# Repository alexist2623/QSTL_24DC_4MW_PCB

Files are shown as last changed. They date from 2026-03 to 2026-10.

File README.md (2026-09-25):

# QSTL carrier PCB

Latest PCB revision, 2026-09-25: two **M1** clearance mounts at the ZIF end, with 1.20 mm plated drills, 1.60 mm lands and 17.40 mm center pitch. Centers are (1.05,1.20) and (18.45,1.20) mm. Direct GND, no thermal relief or paste. Board outline, original six mounts, L2/L4 GND clearance, routing, masks, pin assignments and blind-via spans are preserved. Saved/reopened Altium DRC has zero violations across 16 checked rules, zero unconnected lines, and all 37 nets independently connected. See [validation](QSTL_24DC_4MW_PCB/docs/ZIF_M1_mount_validation.json), [current PCB Top](QSTL_24DC_4MW_PCB/docs/PCB_Top_current.png), and [fresh Gerber/drill ZIP](QSTL_24DC_4MW_PCB/fabrication/JLCPCB_HDI_20260925/QSTL_24DC_6RF_HDI_Gerber_20260925.zip). The ZIP has 96 through holes and 480 L5-L6 blind holes. Native OutJob retains its 20260924 working directory; `script/pcb_end_mounts_20260925/package_m1_cam.py` validates and copies the fresh output to the 20260925 delivery. No new supplier upload was made.

The [current Inventor M1 review](QSTL_24DC_4MW_PCB/Mechanical_Assembly/ZIF_M1_Review/README.md) uses supplied **KS B 1021 M1 x 4** slotted round/pan-head screws (pitch 0.25 mm, head diameter 2.00 mm). Nominal housing clearance is 0.627624 mm, and the centered cable has **0.30 mm clearance to each drilled hole**; see the [dimensioned view](QSTL_24DC_4MW_PCB/Mechanical_Assembly/ZIF_M1_Review/ZIF_Cable_Hole_Clearance.png). Only user-permitted head/cable contact remains in the native fit. Cable height and deformation are not fully verified; this is a nominal fit check. M1.6 and M2 review folders are historical.

Open [QSTL_24DC_4MW_PCB.PrjPcb](QSTL_24DC_4MW_PCB/QSTL_24DC_4MW_PCB.PrjPcb) in Altium Designer. The original project contains six active RF channels, 18 DC-only QD pads and six RF bias inputs. ZIF and SMP are on Top; QD, R0603 and C0402 are on Bottom. All eight SMP positions, six original mounting holes and the 19.5 x 67.9 mm board outline are preserved.

Read [DESIGN_REQUIREMENTS.md](QSTL_24DC_4MW_PCB/docs/DESIGN_REQUIREMENTS.md) before further edits. Helpers are in [script/](script/README.md); the reference PCBs remain read-only.

## QD cavity and pad geometry

The Bottom-entry non-plated pocket is 4.3 x 4.3 mm, centred at (9.75,42.50) mm, with R0.5 internal corners and 1.2 mm depth. It is a fabrication-defined blind pocket, not a through-board cutout or a rendered 3D cavity. Its outline is on Mechanical 2 and its English depth note is on Mechanical 3.

QD pad rows have moved outward by 0.2 mm. The inner pad-end opening is 4.7 x 4.7 mm and the nominal cavity-to-pad gap is 0.2 mm. Pad sizes remain 1.0 x 0.5 mm with 0.7 mm pitch along each row. Pads 1 and 24 remain on the upper edge. The original QD footprint library matches the saved board.

The 4.7 mm inner square is free of GND on L2/L3/L4/L5/L6; Top GND remains under the pocket. RF and DC do not cross the cavity.

## RF and routing stack

From the QD side the stack is **RF / GND / DC / GND / DC / GND**, physically L6/L5/L4/L3/L2/L1. RF uses 0.11 mm width with a 0.2 mm coplanar GND gap, following the supplied 50-ohm JLCPCB HDI calculator geometry. The native stack matches the specified copper/dielectric thicknesses for JLCH06161HN1-1078. Fabricator material Dk, finished copper, mask and width compensation still require confirmation; this is not an impedance simulation or measurement. Delay matching to 1 ps remains deferred.

| Input | Series C / bias R | QD pad | Bias ZIF pin |
|---|---|---:|---:|
| SMP1 | C1 / R1 | 9 | 48 |
| SMP2 | C2 / R2 | 6 | 46 |
| SMP3 | C3 / R3 | 1 | 42 |
| SMP4 | C4 / R4 | 24 | 8 |
| SMP5 | C5 / R5 | 12 | 4 |
| SMP6 | C6 / R6 | 18 | 2 |

SMP7/8 centre pins remain NC. All 24 DC nets use physical ZIF even contacts **2, 4, ..., 48**. Contact **50** and every odd contact remain NC. PCB, schematic and QD symbol-library assignments are synchronized. [PIN_MAPPING.csv](QSTL_24DC_4MW_PCB/docs/PIN_MAPPING.csv) contains the complete correspondence. Each RF path passes through its resistor RF-side pad centre without a separate resistor branch stub. All 12 redundant capacitor pad through-vias are removed.

There are 480 solid GND shield vias: 243 along RF routes, 171 around R/C groups, and 66 in SMP signal rings. They span L6-L5 only, with 0.10 mm holes and 0.25 mm lands. Straight fences use nominal 0.15 mm land-edge spacing (0.40 mm centre pitch). The RF clearance is measured from the RF copper edge to the laser-hole edge: 0.33 mm, corresponding to a 0.435 mm centre offset and 0.255 mm land clearance. Each active SMP uses an equal-angle 13-position grid at radius 0.88 mm; two symmetric RF-exit positions are omitted, leaving 11 vias with 0.421 mm chord spacing. R/C fences stay outside each complete two-pad/body envelope.

The remaining 48 through vias comprise 18 QD DC, six DC-side resistor and 24 ZIF fanout vias. QD RF pads 1/6/9/12/18/24 have no vias because their signals stay on Bottom. R1-R6 each have one via on DC pad 2; the six unused RF-side pad 1 vias have been removed. RF pad 1 connects entirely on Bottom, preserving the through-pad RF path without a via stub. DC uses one internal layer per net, 12 nets on each of L2/L4, with no extra transition vias. DC width is 0.125 mm; Top ZIF escapes are 0.15 mm. The central bus pitch is 0.6 mm and the two internal layers share XY routing space. Straight tracks remain XY/45-degree and RF bends use tangent arcs. Two adjacent DC trunks were offset locally by 0.10/0.05 mm to preserve clearance after the QD move.

## Solder mask and paste

Upper R3/C3 and R4/C4 moved upward by 2.0 mm, giving 2.05 mm minimum clearance to QD pads. After the earlier upward and inward adjustments, both lower pairs now sit at 70% of their previous distance from the X=9.75 mm board centreline. R1/C1 moved another 1.365001 mm inward, and R5/C5 another 1.470000 mm inward, as rigid pairs with Y, spacing and rotations preserved. Pair pad-envelope centres are X=12.935000 and X=6.319999 mm. RF/DC endpoints, the two resistor DC vias, rectangular masks and shield fences follow the new positions. The two DC terminations were simplified to one 45-degree approach on their existing L4 layer; no pin remapping or transition via was needed.

The QD Bottom wire-bond field is unmasked. All six R/C groups now have rectangular solder-control areas extending 0.90 mm beyond their pad-group bounds, increased from 0.30 mm. The Bottom ZIF fanout-via array has a rectangular mask boundary with 0.40 mm land margin. RF outside the QD field retains its protected mask strip. SMP solder-control masks remain. All six mounting lands and their surrounding rings are unmasked on both faces and join GND polygons directly, without thermal relief. Shield vias retain explicit tenting overrides in protected areas.

No via-specific paste primitives are present. Paste is disabled on all 40 SMP and eight mounting pads; the 101 SMD pad apertures are preserved. SMP mask remains; mounting mask removal is separately authorized by the later user instruction.

## Current validation and outputs

The saved original PCB contains 22 components, 149 pads, 37 named nets, 228 signal tracks, 20 RF arcs and 528 vias. Save/reopen verification reports **zero connection lines and zero violations across 16 enabled Altium DRC rules**. An independent graph verifies all 37 nets and the actual L5-L6 shield spans. The current native schematic compile reports zero violations and matching assignments. The current PCB/CAM reports are `docs/ZIF_M1_mount_validation.json`, `docs/connection_validation.json` and `fabrication/JLCPCB_HDI_20260925/CAM_validation.json`. Earlier reports below retain their historical revision hashes.

[Saved-board validation](QSTL_24DC_4MW_PCB/docs/DC_Even_ZIF_validation.json) | [Connectivity](QSTL_24DC_4MW_PCB/docs/connection_validation.json) | [Altium DRC](QSTL_24DC_4MW_PCB/docs/DC_Even_ZIF_DRC.html) | [Schematic validation](QSTL_24DC_4MW_PCB/docs/schematic_validation.json)

[Current DC routing](QSTL_24DC_4MW_PCB/docs/DC_Even_ZIF.png) | [ZIF contact detail](QSTL_24DC_4MW_PCB/docs/DC_Even_ZIF_detail.png)

[R/C mask detail](QSTL_24DC_4MW_PCB/docs/RC_mask_detail.png) | [ZIF mask detail](QSTL_24DC_4MW_PCB/docs/ZIF_mask_detail.png)

[RF and shields (preceding revision)](QSTL_24DC_4MW_PCB/docs/RF_only.png) | [QD detail (preceding revision)](QSTL_24DC_4MW_PCB/docs/QD_detail.png) | [Board overview (preceding revision)](QSTL_24DC_4MW_PCB/docs/layout.png)

[Fabrication companion package](QSTL_24DC_4MW_PCB/fabrication/RF50_QD_cavity/README.md) contains the Bottom Blind Slots documentation, stack data and JLCPCB notes. The separate 2026-09-22 Gerber/HDI quote package predates the current DC remap. Regenerate the complete CAM package before production; the prior upload does not contain this change.

Current reports are DC_Even_ZIF.json, DC_Even_ZIF_validation.json, validation.json, connection_validation.json, schematic_validation.json, placement_mask_validation.json, DC_Even_ZIF_DRC.html, native_paste_audit.txt and native_reopen_check.txt. Earlier RF/DC/model/mask reports and images are historical and retain their earlier revision hashes; do not use them as current signoff.

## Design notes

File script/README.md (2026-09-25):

# PCB working scripts

The latest M1 ZIF-end mounts, native save/reopen audit, Inventor standard-hardware fit review and fresh CAM package are in [pcb_end_mounts_20260925/](pcb_end_mounts_20260925/README.md). The current Gerber ZIP is under `fabrication/JLCPCB_HDI_20260925/`. Native L2/L4 GND pour work is in [dc_ground_pour_20260924/](dc_ground_pour_20260924/README.md). Completed Rev E DWG refresh is in [dwg_gerber_refresh_20260924/](dwg_gerber_refresh_20260924/README.md). Earlier CAM/quote records are historical.

The current 2026-09-23 DC remap is in `dc_even_zif_20260923/`: physical J1 contacts 2..48 even only, with pin 50 and every odd contact NC. `FixZIFPads.pas` records the required `SetState_InNet` update and native connectivity rebuild. Saved-file connectivity, schematic correspondence, DRC, preserved RF/mask geometry and DC previews are verified there. Mutation scripts are one-time records; do not rerun them against a different starting revision.

The complete native Altium CAM package and JLCPCB HDI quote record from 2026-09-22 are generated/validated by `jlcpcb_hdi_quote_20260922/package_cam.py`. `ReopenAudit.pas` reopens the original saved board and runs native DRC without changing the design. Quote evidence is stored in `QSTL_24DC_4MW_PCB/fabrication/JLCPCB_HDI_20260922/`.

Create and run helper code inside this repository's `script/` directory. Write Markdown, code comments and technical annotations in English. Communicate with the user in Korean.

Read [DESIGN_REQUIREMENTS.md](../QSTL_24DC_4MW_PCB/docs/DESIGN_REQUIREMENTS.md) and [AGENTS.md](../AGENTS.md) before editing the original `QSTL_24DC_4MW_PCB/` project.

Current lower R/C pair movement to 70% of the previous centreline distance and QD RF-via removal are in `lower_rc_70pct_20260921/`. The preceding removal of unused resistor RF vias is in `remove_resistor_rf_vias_20260921/`. The preceding R/C placement, rectangular-mask and hole-edge shield work is in `rc_mask_clearance_20260921/`. The preceding component-fence/mount work is in `shield_rc_ring_20260921/`; earlier dense fences are in `shield_spacing_20260921/`. The preceding RF50, QD pad/cavity and mask work is in `rf50_hdi_milling_20260920/`. Previous mask work is in `mask_ground_20260920/`; previous RF/DC routing work is in `rf_six_inward_20260920/`. `_support/` contains local parsing, rendering and schematic helpers; older revision names there do not denote a separate final project.

Use `script/.venv/Scripts/python.exe -X utf8` with `requirements.txt`. Native Altium scripts must target the original project and be followed by save/reopen checks. Python validators read saved documents. Current reports must match the saved PCB SHA-256.

Previous mutation scripts such as `ApplyRF6.pas`, `FixRF6.pas`, `AdjustRF6.pas`, `FinalDC.pas` and `FixModels.pas` are one-time change records. They assume a specific starting state and must not be rerun blindly. The preceding via-paste validator is historical: the latest user instruction explicitly removes via-specific paste apertures while retaining normal SMD paste.

Keep reference designs read-only, avoid extra DC transition vias, and preserve the current RF/soldering masks and non-Top QD GND exclusions during later edits.

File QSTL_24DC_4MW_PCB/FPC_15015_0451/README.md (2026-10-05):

# Molex 15015-0451 FPC reconstruction

Manufacturing documentation (reviewed 2026-10-05): [DRC and manufacturability](../docs/FPC_DRC_AND_MANUFACTURABILITY.md) and [order specification](../docs/FPC_ORDER_SPECIFICATION.md). The saved copper remains 18 um; 12 um is an unimplemented alternative. The current contact gap does not meet JLCPCB's regular 18 um spacing requirement. Archived zero-violation reports are not fabrication approval.

Created 2026-10-02 for the Molex 502598-5193 carrier connector. Open `FPC_15015_0451.PrjPcb` in Altium Designer. This is a separate cable project; the carrier PCB and schematic are unchanged.

## Scope and nominal dimensions

The editable PCB reproduces the public nominal cable outline and staggered, same-face contact pattern. It is not Molex's proprietary production artwork or a certified replacement cable. All 51 conductors are present, including contacts unused by the carrier.

| Feature | Implemented nominal value |
| --- | --- |
| Part | Molex 15015-0451 / 0150150451 |
| Length | 101.60 mm; marketed as 102 mm |
| Width | 15.60 mm |
| Circuit count / pitch | 51 / 0.30 mm |
| First / last contact centre | 0.30 / 15.30 mm across the width |
| Contact face | Type A; both ends on Top |
| Corner radius | R0.20 mm; native arc outline segments |
| Exposed contact length | 3.00 mm at each end |
| Back stiffener length | 4.00 mm at each end |
| Contact neck / finger width | 0.10 / 0.30 mm |
| Body conductor width | 0.20 mm |
| Contact transition stations | 0.15, 0.25, 1.10, 1.20, 2.00 and 2.10 mm from the end |
| Copper | 18 micrometres, one conductive layer |
| Base PI + adhesive | 45 micrometres |
| Coverlay PI + adhesive | 50 micrometres |
| End stiffener + adhesive | 150 micrometres, on the back |
| Contact thickness requirement | 0.20 +/- 0.03 mm |
| Surface finish specified by source | Hard gold at least 0.0508 micrometres over nickel at least 2.54 micrometres |

The base/copper/coverlay body sums to 0.113 mm. The exposed end sums to 0.213 mm before plating, within the published 0.20 +/- 0.03 mm end requirement. The 1 mm coverlay/stiffener overlap sums to 0.263 mm before plating. These layer sums use the published nominal composite thicknesses; adhesive compression and detailed production tolerances are not known.

## Altium representation

- Top Layer contains the 51 copper nets. Each end array is a native component with 51 numbered pads and copper regions that define the staggered fingers. The small native pad rectangles lie entirely within their corresponding copper regions.
- Top Solder is used as the **coverlay opening artwork**, not a solder-resist application instruction. Two full-width 3 mm end openings expose the mating fingers.
- The stored master/substack is flex, with one copper layer, the PI base and the upper coverlay. No bottom copper, bottom solder mask, holes or vias are present.
- Mechanical 2, named **Back stiffener boundary**, defines the two 4 mm back stiffener extents. Stiffeners are fabrication annotations, not separate native rigid-flex substacks or 3D solids. Their material/thickness is specified in this document and the review section drawing.
- Mechanical 1 contains English fabrication annotations. No printed silkscreen is required. All contact pad paste generation is disabled.
- `contact_mapping.csv` labels matching physical conductors A1-B1 through A51-B51, viewed from the same global mating face. These cable labels do not imply the pin-number orientation of two separately installed connectors; connector orientation must be considered when wiring an assembly.
- The 0.0707 mm clearance rule follows the drawing's opposed 45-degree stagger transitions: 0.10 / sqrt(2) = 0.0707107 mm. Straight body trace clearance is 0.10 mm. This is the geometry of the copied cable, not a generic PCB fabrication capability claim. No DRC rule was disabled to hide a violation.
- Dielectric constant 3.5 is a modelling placeholder, not a released Molex material property. No controlled-impedance claim is made for this cable.

## Source reconciliation

1. [Molex product page](https://www.molex.com/en-us/products/part-detail/150150451): 51 circuits, 0.30 mm pitch, Type A, 102 mm catalog length; compatibility with the 502598 series.
2. [Current Molex family sales drawing, 150150001PSD000 Rev B, 2023-08-08](https://www.molex.com/content/dam/molex/molex-dot-com/products/automated/en-us/salesdrawingpdf/150/15015/150150445_sd.pdf): staggered contact dimensions, width formula, composite layer thicknesses and end-thickness tolerance. Its searchable dimension text was read; direct local PDF download was unavailable during this task.
3. [Legacy original Molex sales drawing, SD-15015-001 Rev B, 2013-01-23, distributor mirror](https://pdf.icgoo.net/productinfo/allpdf/72b4076c-1cfe-31fc-a247-91ae0da5b5bd.pdf): the 150150451 row explicitly gives 101.6 mm length and 15.6 mm width. The local PDF was rendered and visually checked, including the staggered pattern. A copy is retained under the repository helper's `reference/` directory.
4. [Molex family product specification, PS-15015-001 Rev C](https://www.molex.com/content/dam/molex/molex-dot-com/products/automated/en-us/productspecificationpdf/000/000000/PS-15015-001-001.pdf): electrical/environmental family properties and generic construction requirements.

The sources are not fully consistent: the family product specification has a width formula that adds 0.10 mm, a nominal 0.10 mm conductor width, and a 0.135 mm stiffener value; the sales drawing gives 15.6 mm width, a 0.20 mm body conductor detail, and a 0.150 mm stiffener-plus-adhesive callout. This reconstruction follows the **sales-drawing geometry**. The older drawing has tighter exposure/stiffener tolerances than the current drawing. No unpublished adhesive formulation, copper temper, exact material grade, finished compression, bend lifetime or manufacturing qualification has been inferred. Resolve these differences with the manufacturer before treating the reconstruction as a production-equivalent part.

## Validation and outputs

- `native_validation.txt`: saved-file reopen, one signal layer, zero stored unrouted connections and successful native Altium DRC.
- `Native_DRC.html`: 13 enabled rule checks, zero violations after applying the drawing-derived minimum copper gap.
- `saved_geometry_validation.json`: independent saved-binary geometry checks, including continuity, isolation, pitch, copper layer, stack thicknesses, no vias/drills, and original-carrier hash preservation.
- `FPC_15015_0451_review.png`: review image generated from the saved native copper, with dimensional overview, contact detail and construction section. It is a geometry render, not an Altium screenshot.
- `nominal_geometry.json` and `contact_mapping.csv`: editable nominal specification and physical conductor mapping.

The initial project wrapper contained an invalid optional enum (`ClassGenNCAutoScope=All`). It has been removed from both the saved project and its generator. Native PCB reopen and DRC succeeded; final project-tree registration after this wrapper correction remains unverified because the Altium UI automation repeatedly returned an unresponsive/stale error dialog. The PCB document remains available independently of the project wrapper.

Git delivery of this source cable and the two derivative adapters was requested on 2026-10-03. No Gerber fabrication release, vendor upload or purchase was performed.

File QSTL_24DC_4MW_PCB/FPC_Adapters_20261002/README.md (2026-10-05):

# FPC adapter designs

Manufacturing documentation (reviewed 2026-10-05): [DRC and manufacturability](../docs/FPC_DRC_AND_MANUFACTURABILITY.md) and [order specification](../docs/FPC_ORDER_SPECIFICATION.md). These documents compare saved rules with supplier limits and list the unresolved order settings. Copper remains 18 um per layer; 12 um has not been selected or applied.

Updated 2026-10-02. Open each `.PrjPcb` to load its PCB and schematic. These are additional designs; the original carrier, straight cable and read-only references are preserved.

| Design | Wiring and geometry | Saved validation |
| --- | --- | --- |
| ZIF_to_2xZIF | All 51 contacts branch C.n = A.n = B.n; output tips separated by **70 mm** | Native reopen and DRC: 0 violations; rebuilt connections: 0; 532 independent checks |
| ZIF_to_DSUB25 | Anton's NorComp Micro-D mapping; 25 signals on even ZIF contacts | Native reopen and DRC: 0 violations; rebuilt connections: 0; 87 independent checks |

Both PCBs were rebuilt through Altium's native API and saved normally. The final saved files were reopened in a fresh Altium process for DRC and connection rebuilding. `Native_DRC.html`, `native_validation.txt`, `geometry_validation.json` and `native_status.json` provide the evidence for each board. The review PNGs show actual saved copper with dimensions; they are not Altium screenshots.

The branch's first native schematic compile reported three missing footprint models. Component-specific local `.PcbLib` files were recovered from actual saved PCB pad/region geometry, and explicit model links plus project membership were added. `footprint_recovery.json` records source hashes and coordinate round-trip checks. Native library reload and schematic recompile remain unverified because Altium window activation times out. Independent saved schematic wire/pin correspondence is verified. Restart Altium and run the prepared read-only `CompileOnly.PrjScr` with both final projects open to finish this check; do not run the obsolete offline PCB writers against these final files. Existing `native_compile.txt` reports predate library recovery and are not final compile passes.

The branch's 420 mm overall length and 10 mm strip-to-strip clear gap remain provisional interpretations of the sketch. The DSUB adapter's 40 mm length, 31 mm base and 1.6 mm finished connector-area backing are design assumptions. The original straight 101.6 mm cable was not shortened; the new branch's A-to-B tip separation is 70 mm.

These files are not released for fabrication. The inherited 0.0707105 mm contact gap, small DSUB PTH annulus, fine branch drilling and finished flex/stiffener stack require supplier acceptance. Native DRC confirms the stored design rules, not universal supplier capability.

Git delivery to the existing repository was requested on 2026-10-03. No supplier upload, fabrication release or order was performed.

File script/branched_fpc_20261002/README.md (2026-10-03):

# Adapter helpers and current state

The final designs are under `QSTL_24DC_4MW_PCB/FPC_Adapters_20261002/`.

## Safe verification

- `validate_branch.py` and `validate_dsub.py` read the final saved designs, verify copper/contacts/masks and regenerate dimensional PNGs and geometry reports.
- `CompileOnly.PrjScr` is a read-only native schematic compile/export helper. After restarting Altium, open both final `.PrjPcb` files (including their local footprint libraries), then run `CompileOnly.pas > CompileOnly`. Inspect every violation and compare its recovered pin map with `schematic_correspondence.json` before marking compile as passed.
- `ColdAudit.PrjScr` opens saved final boards, rebuilds connectivity and runs native DRC. It is unnecessary unless the saved boards change. It does not save an altered PCB.
- `recover_footprint_libraries.py` recovers component-specific pad/region geometry, adds explicit schematic model links and project membership. It preserves PCB bytes and stores original schematic/project backups in `before_library_recovery/`. Native library loading remains to be checked.
- `publish_validation_status.py` currently publishes the verified PCB evidence and the pending native library/compile limitation. Update its status logic when native compilation actually passes; do not claim a pass from this documentation writer.

## Obsolete or single-use scripts

Do not run offline PCB writers, `BuildNativeBoth`, `NativeFinish`, `FinalAudit` or `FixViaFlags` against populated final documents. The native PCB rebuild and mask repair have already been applied. `NativeFinish` would add duplicate coverlay regions if repeated. `FinalAudit` performs saves and is superseded by the separate read-only audits. `FixViaFlags` arose from an incorrect interpretation of generic inherited via cache flags; saved native mask overrides already close the via openings. Its attempted unsaved changes must not be promoted to final files.

`native_work/` and `before_native_validation/` contain historical build inputs/results, not final deliverables. The final review PNGs are rendered from actual saved copper, not captured from Altium.

The current Altium sessions did not respond to window activation. The first branch compile reported missing models; libraries were then supplied on disk. Pending work is native reload/compile and verification of those explicit library links. Git delivery was requested on 2026-10-03; the pending native validation remains documented and no fabrication release has been performed.

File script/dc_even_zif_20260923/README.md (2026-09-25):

# Even-contact ZIF DC remap

The original project now uses physical J1 contacts 2, 4, ..., 48 for 18 QD DC inputs and six RF bias inputs. Contact 50, every odd contact and connector mounts 52/53 remain NC. No component positions, pad sizes, RF geometry, shielding or layer stack were changed.

The existing 24 ZIF fanout vias were moved into two rows. Each net uses exactly one internal layer: 12 on L2 and 12 on L4. DC routing below Y=20 mm and local Top/Bottom ZIF mask protection were rebuilt. The schematic, QD symbol library and `docs/PIN_MAPPING.csv` follow the physical even-contact map.

## Saved-file validation

- `audit_connectivity.py`: all 37 nets form continuous copper graphs; 0 saved connection lines, 48 signal through vias and 480 L5-L6 GND blind vias.
- `verify_final.py`: native geometry, clearance rules, QD cavity/GND exclusion, mask, paste and DRC checks.
- `verify_refinements.py`: rectangular masks, solid mounting-hole copper and retained RF shield rings.
- `finish.py`: exact RF/component/pad preservation, even contacts, one internal layer per DC net, XY/45-degree directions, at most 45-degree turns, schematic/PCB/library consistency and actual saved-geometry previews.
- Native save/reopen DRC: 0 violations across 15 enabled rules. Schematic export: 0 reported violations and matching 37 named nets plus 31 singleton NC nets. The API compile-return flag was False and is retained verbatim in `schematic_validation.json`.

The final source hash is in the validation JSON files. Previews are generated from the saved PCB primitives, not synthesized illustrations or screenshots. `DC_Even_ZIF.png` shows the overlay and both DC layers; `DC_Even_ZIF_detail.png` shows all connector contacts and contact 50 NC.

## Change-record workflow

`inspect_baseline.py`, `prepare.py` and `build_native.py` record the initial guarded change preparation. `ApplyEvenDC.pas` performs the native mutation. `prepare_audits.py` promotes the prepared schematic/library after closing them in Altium. `FixZIFPads.pas` explicitly sets the pad InNet flag and rebuilds net connectivity before saving and reopening. This flag is required for previously unconnected pads to retain their new nets on save. All native paths must use single Pascal backslashes to avoid duplicate Free Document aliases.

Mutation scripts and the saved `before.*` files belong to this one-time revision. Do not rerun them blindly against a later PCB. Read-only validators and `finish.py` may be rerun to refresh the matching reports/previews. Prior Gerber/HDI quote packages are historical and were not regenerated or uploaded for this request.

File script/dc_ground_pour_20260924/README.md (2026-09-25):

# DC-layer ground pour and CAM refresh

Completed on 2026-09-24 in the original Altium project. The user confirmed GND pour around existing L2/L4 DC traces. Actual saved-copper images were delivered before CAM generation.

## Saved design

`ApplyGroundPour.pas` initially added `L2_DC_GND` and `L4_DC_GND` through Altium's native PCB API. The user's subsequent widening request was implemented by `WidenGround.pas`: a dedicated 0.20 mm `DC_GND_GAP_0P2` rule applies to GND on L2/L4, and the general 0.15 mm clearance rule excludes that scope. Both polygons were rebuilt and the original PCB was saved, reopened and independently validated.

- L2 grounded copper: 900.799391 mm2; L4: 921.449974 mm2. One connected region per added layer; no floating islands.
- Nominal DC clearance: 0.20 mm; minimum saved signal-copper gap: 0.199997029 mm (within the native 2.54 nm coordinate grid). Trace-only minimum is approximately 0.199999 mm. Trace-to-trace minima remain 0.224998 mm on L2 and 0.274998 mm on L4.
- QD GND exclusion retained on every non-Top layer; Top GND retained.
- Existing tracks, arcs, pads, vias, components, net identities and masks preserved. L1/L3/L5/L6 ground geometry is unchanged. The dedicated DC clearance rule is the only new rule; existing clearance priorities were renumbered and the general rule scope was narrowed accordingly. Native save also materialized zero-valued Manhattan-length statistics and closed the unused polygon terminal vertices onto vertex zero.
- All six mechanical GND annuli connect directly to the new pours without thermal relief.
- All 37 copper nets connected; zero stored connection lines and zero native DRC violations across 16 checked rules after save/reopen, including the new 0.20 mm DC pour rule.
- Native schematic compilation: zero violations; physical assignments match. J1 uses even contacts 2..48; 50 and odd contacts remain NC.
- Existing 480 L5-L6 shield microvias and 48 signal through vias preserved; no added DC transitions.
- Native paste audit checked 147 pads; mask/paste geometry unchanged.

Source SHA-256: `e252bd2d1eb66c667f9d9521f6877922dba3e0579a901d9490fa90835c539c07`.

Pre-widening (0.15 mm pour) SHA-256: `84dcebb1a5cb88b31b997d4bbd6eb5fdd2adb6653206d6d17162d2bf9df86361`. Backup: `before_clearance_0p20.PcbDoc`.

Saved PCB SHA-256: `833555d572fb9945703213acef1ecd809d7eb3ce4a73d5e467c577d3ef70bc90`.

`verify_saved.py` records checks in `validation.json` and `../../QSTL_24DC_4MW_PCB/docs/DC_GND_pour_validation.json`. `preview_ground.py --saved` renders actual native copper to `../../QSTL_24DC_4MW_PCB/docs/DC_GND_pour.png`. Its default mode and `DC_GND_pour_preview.png` are historical proposals, not final results. Mutation scripts are one-time records and must not be rerun against a later board.

## Manufacturing outputs

`prepare_outjob.py` transfers the original project's saved Gerber/NC-drill settings into `HDI_Fabrication.OutJob`. The OutJob belongs to the original project and selects its PCB. Altium regenerated both outputs into `fabrication/JLCPCB_HDI_20260924/Native_CAM` after the 0.20 mm change. Export did not change the PCB.

`package_cam.py` checks timestamps, source hashes, 12 Gerbers, actual GND pours against native geometry, all 94 plated through holes, all 480 laser holes, coordinates/diameters, L5-L6 layer pair, outline and separate Bottom blind-pocket contour. Gerber GND boundaries match native copper within the 0.0002 mm comparison tolerance.

Delivery: `fabrication/JLCPCB_HDI_20260924/QSTL_24DC_6RF_HDI_Gerber_20260924.zip`. Includes requested stack, 50-ohm geometry and Bottom 4.3 x 4.3 x 1.2 mm pocket documentation. Paste/stencil outputs are excluded. `CAM_validation.json` and `Native_DRC.html` accompany the ZIP.

Earlier startup/login and standalone-dialog problems were resolved; the native OutJob completed CAM generation. No supplier upload, new quote, order or Git push was performed for this refresh.

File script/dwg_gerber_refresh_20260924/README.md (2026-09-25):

# Drawing and PCB fabrication refresh - 2026-09-24

## Completed

- Regenerated native plate-only Rev E DWGs from the saved 1.6 mm/C1.6 support geometry, preserving the central deck, device, supplied screws and source CAD files.
- Reopened the combined master and all five single-sheet DWGs. Confirmed five ISO A3 sheets, 46 attached native dimensions without overrides, IPN explosion and removed prose blocks.
- Corrected PowerShell 5.1 source encoding to UTF-8 with BOM for diameter and degree symbols; regenerated all outputs and visually inspected all five PDF pages.
- Delivered `QSTL_Plate_DWG_Package_RevE.zip` in the mechanical model directory. `build_dwg.ps1`, `verify_dwg.ps1` and `package_dwg.py` reproduce the drawing workflow. `DWG_README.md` is the package README source.
- Read-only PCB validation confirmed all 37 copper nets connected, zero saved connections, 24 even ZIF contacts 2..48, pin 50 NC, 48 signal through vias and 480 L5-L6 shield microvias. The pre-pour PCB SHA-256 was e252bd2d1eb66c667f9d9521f6877922dba3e0579a901d9490fa90835c539c07.

## PCB pour and manufacturing outputs completed

The user confirmed GND fill around L2/L4 DC traces and then requested widening its signal clearance to 0.20 mm. Application, saved-copper images and CAM packaging are recorded in `../dc_ground_pour_20260924/README.md`. Images were delivered before new CAM generation.

After startup recovery and user login, `AuditAll.pas` ran against the saved/reopened original PCB. Fresh `reopen_check.txt`, `native_paste_audit.txt`, `schematic_compile.txt` and `fabrication/JLCPCB_HDI_20260924/Native_DRC.html` confirm zero connection lines, zero DRC violations across 16 checked rules, preserved paste and matching schematic assignments. The independent graph verifies all 37 copper nets.

Current PCB SHA-256: `833555d572fb9945703213acef1ecd809d7eb3ce4a73d5e467c577d3ef70bc90`.

`HDI_Fabrication.OutJob` generated fresh Gerber and separate laser/through drills. The validated delivery is `fabrication/JLCPCB_HDI_20260924/QSTL_24DC_6RF_HDI_Gerber_20260924.zip`. Earlier CAM packages remain historical. No supplier upload or Git push was performed.

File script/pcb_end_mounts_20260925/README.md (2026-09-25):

# M1 ZIF-end PCB mounts

Current geometry: MH7/MH8 at X1.05/18.45, Y1.20 mm, with 1.20 mm plated drills, 1.60 mm lands and 17.40 mm pitch. Original outline and six mounts persist. All eight mounts use direct GND, no thermal relief and no paste.

`ApplyM1.pas` records the original-PCB mutation, native repour, save/reopen DRC, paste audit and schematic check. `before_m1.PcbDoc` preserves the immediate M1.6 predecessor. These mutation scripts are one-time records; do not rerun blindly. Historical M2/M1.6 mutation and review scripts are superseded.

Current saved-file validation: `verify_m1_saved.py`, together with `../dc_even_zif_20260923/audit_connectivity.py` and `../dc_ground_pour_20260924/preview_ground.py --saved`. It verifies original pads/routes/vias/components, masks, GND/QD conditions, schematic mapping, DRC and independent continuity.

`generate_m1_round_member.ps1` obtains the genuine KS B 1021 M1 x 4 member. `prepare_m1_review.py` exports saved PCB and embedded connector geometry, plus a dimensional cable envelope. `build_m1_review.ps1` creates/reopens the native Inventor assembly, checks interference/minimum distances, and exports STEP and views. Run Inventor COM scripts using Windows PowerShell 5.1. `render_m1_clearance.py` provides the explicit dimensioned top view; `finalize_m1_review.py` links reports and updates documentation. The output is `Mechanical_Assembly/ZIF_M1_Review/`.

After native Altium `HDI_Fabrication.OutJob` export, `package_m1_cam.py` checks fresh output, 96 through holes, 480 L5-L6 blind holes, DC GND Gerber geometry and preserved silkscreen, then builds the current 18-file ZIP. `prepare_m1_deliverables.py` records how the M1-specific scripts were adapted from the preceding review; do not rerun it over finalized files.

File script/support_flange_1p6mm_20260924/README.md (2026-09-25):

# Support flange 1.6 mm - final revision D

Final user requirements: 1.6 mm rod-contact flanges, full-thickness 45-degree outer bevels (C1.6), plain diameter 3.4 mm mounting holes, original M3 threaded rods and original fastener insertion direction. Flange threading was explicitly cancelled. The central deck remains 4 mm. Preserve the central pocket-reference alignment.

`apply_supports.ps1` updates native supports, eight screw seating transforms, STEP exports and assemblies. Its `before/` snapshot contains the prior 2 mm revision. Do not overwrite that baseline. `set_final_thickness.py` and `prepare_checks.py` are one-time helper preparation records, not regeneration commands.

Run `read_pocket_placement.ps1` to read nested saved transforms, then `verify_assembly.py`, `verify_flange.py` and `verify_native_saved.ps1`. They check valid solids, exact parameter values, native thread absence at flange holes, retained deck threads, protected part hashes, flange geometry, screw seating, actual contact/interference and pocket-reference alignment. The full model has 24 occurrences. The pocket reference is 0.300 mm from the milling floor toward its opening, not the carrier bounding-box centre.

`render_native.ps1` exports the literal cylinder axial view and the support end view. `verify_assembly.py` also makes the labelled STEP section through the pocket, whose centre can be obscured by crossbars in the literal native view.

`build_dwg.ps1` and `verify_dwg.ps1` update/reopen the six native Rev D DWGs (five A3 sheets, 46 associated dimensions). Render and inspect the PDF companion. Run `prepare_delivery.py`, then `package_dwg.py` to produce the current Rev D plate-only drawing package. Keep previous revision ZIPs historical.

The unchanged M3x8 rod screws now project 0.4 mm beyond the provisional 6 mm rods. Their flat head-bearing contact is 67.11%. Existing reference sleeve and tiny device screw fillet/slot intersections remain reported; do not assert that the complete installation is interference-free. No washers, shortened hand-built screws or unrequested reference-part edits were introduced.

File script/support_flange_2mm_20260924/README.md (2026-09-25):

# Support flange revision - 2026-09-24

The user section sketch selects the outer rod-contact flange: 4 to 2 mm and a 45-degree outer bevel. The implemented bevel is C2, spanning the full new flange thickness. The central deck remains 4 mm, and the rod mating plane, device placement and pocket-axis alignment are unchanged.

`apply_supports.ps1` is a one-time guarded mutation with a pre-change backup in `before/`. It saves native support IPTs, assembly placements and STEP exports; moves eight existing rod screws by 2 mm to their new seating plane; and produces native previews. Do not rerun it on already-modified models.

Validation and delivery order:

1. `verify_assembly.py`: full STEP geometry, seating/interference, unchanged reference parts, device alignment and rod contact.
2. `verify_flange.py`: independent requested cuts, valid solids, volume and 20,000 deterministic point classifications per part, bevel planes and actual screw-bearing contact. Coincident-face boolean differences produce invalid kernel results, so they are not used as evidence of equivalence.
3. `verify_native_saved.ps1`: independent saved IPT copies, native features and threads.
4. `build_dwg.ps1`, then `verify_dwg.ps1`: six native Rev C DWGs, five A3 sheets and 46 associated dimensions. Render the PDF companion and inspect all sheets after changes.
5. `prepare_delivery.py`, then `package_dwg.py`: update documentation and create the Rev C plate-only delivery.

The C2 bevel leaves 60.60% of each rod screw flat bearing area in contact. No washers or substitute hardware are introduced. Existing device screw fillet/reference-slot intersections remain in the assembly report. The revision is geometrically checked, not structurally qualified. Rev B delivery files are historical; Rev C is current.

All source comments and design records are English. Original PCB/reference CAD and the flat adapter variant are unchanged by this revision.

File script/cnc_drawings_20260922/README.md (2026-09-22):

# Native split-mount drawing workflow

Run PowerShell helpers under Windows PowerShell with Inventor 2027 running. Use the repository `script/.venv` for Python. The saved Rev B CAD and DWG files are the deliverables. Ignored `tmp/` inspection outputs and pre-edit backups are not part of the delivery.

- `generate_content_center_fasteners.ps1`: generate actual supplied DIN 7991 M3x10 and ISO 4762 M3x8 members, retaining Content Center identity and source hashes.
- `replace_content_center_fasteners.ps1`: update current assembly occurrences and countersink fit; no washers are installed.
- `add_device_relief_grooves.ps1`: one-time native feature creation with a duplicate-feature guard. Do not rerun against the already relieved plate.
- `build_native_dwg.ps1`: rebuild five sheets, six native DWGs and the PDF from saved model geometry and the existing native IPN.
- `verify_native_dwg.ps1` / `verify_standard_hardware.ps1`: reopen validation, native dimensions, standard hardware and thread metadata.
- `package_dwg.py`: verify delivery hashes and produce the Rev B ZIP.
- `inspect_device_reliefs.py` / `verify_device_reliefs.py`: measurement and independent relief checks. The latter uses ignored pre-edit STEP backups from the original session.
- `../probe_rod_inspection/verify_dropped_adapter.py`: saved assembly geometry, placement and interference audit; unresolved device-slot intersections are explicitly reported.

Other helpers retain reference-inspection and prototype history. Older prototype and presentation preparation builders use the superseded illustrative screw and must not overwrite the delivery. Use the current Content Center replacement and native drawing workflow for updates.

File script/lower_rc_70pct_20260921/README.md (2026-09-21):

# Lower R/C placement at 70% of centreline distance

This revision edits the original PCB only. The schematic and QD footprint library remain unchanged; no pin remap is required.

- Translate R1/C1 by -1.36500108 mm X and R5/C5 by +1.46999960 mm X. The centre of each pair's pad envelope is at 70% of its previous distance from X=9.75 mm. Y, spacing and rotations remain unchanged.
- Remove six unused QD RF through vias at pads 1/6/9/12/18/24. Keep 18 QD DC vias, six resistor DC vias and 24 ZIF fanout vias. Capacitor and resistor RF pads remain via-free.
- Reconnect S1/MW1/S5/MW5 using XY/45-degree straight segments with tangent bends. MW1 uses 0.15 mm tangent radii for its small lateral adjustment; other changed bends use 0.30 mm radii. Simplify ZIF21/ZIF02 terminal approaches on their original L4 layer without extra vias.
- Regenerate 0.90 mm rectangular R/C masks and 480 solid L5-L6 shields: 243 RF-fence, 171 R/C-perimeter and 66 equal-angle SMP-ring vias. Preserve the hole-edge offset, no-interpad-via envelopes and cavity/ground/paste requirements.
- Move only the C1 reference label downward by 1.2 mm to resolve the resulting silk collision.

`prepare_move.py` and `prepare_shields.py` reuse the checked-in native geometry writers and guard the expected starting state. `ApplyMove.pas`, `ApplyShields.pas` and `FixLabel.pas` are one-time native mutations; do not rerun on a different revision. `before.PcbDoc` is a local ignored backup.

Validation reads the saved native PCB: exact requested moves and unaffected geometry, 37-net physical copper graph, one internal DC layer per net, XY/45-degree routing, tangent RF bends outside pads, RF paths through resistor pad centres, mask rectangles, 101 normal SMD paste apertures, QD ground exclusions, solid mounting connections, and 15 enabled Altium DRC rules after reopening. All reports must match the current PCB hash. Existing short track endings wholly inside QD pads 1/24 are recorded separately from exposed trace bends.

`publish_outputs.py` refreshes previews and fabrication companion files; this is not a complete production CAM release. `finalize_reports.py` updates current-report pointers after verification.

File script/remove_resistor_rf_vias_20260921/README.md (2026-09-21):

# Remove unused resistor RF-side vias

Saved original PCB SHA-256: `b173b9c072e841f28fbcb25979e917d688061a3a3b2fa08889f660b3afcafd10`.

Removed exactly six 0.50 mm land / 0.25 mm drill through vias, one at RF pad 1 of each R1-R6 (MW1-MW6). The RF path remains on Bottom and passes through the resistor pad centre. Each resistor retains its DC pad 2 via. QD and ZIF vias remain.

Saved counts: 54 signal through vias, 470 L5-L6 GND shield microvias, 524 total vias. All 37 nets are physically connected, with zero stored connection lines and zero violations across 15 enabled native Altium DRC checks after save/reopen.

`before.PcbDoc` is the recovery copy. `prepare.py` and `RemoveRFVias.pas` are one-time scripts guarded against the exact starting revision and six via targets. Only the six vias were removed and GND polygons repoured. Saved component/pad/track/arc/text/fill/net streams and the schematic/library hashes are checked against the baseline. The masks, QD ground exclusions and remaining via locations/spans are validated independently. The requirement is recorded in AGENTS.md and DESIGN_REQUIREMENTS.md to prevent reintroduction.

`audit_connectivity.py`, `verify_final.py`, `verify_refinements.py`, `ReopenAudit.pas` and `AuditPaste.pas` contain validation. `publish_outputs.py` and `finalize.py` refresh previews, documentation and fabrication companion revision hashes. No Git push or supplier submission was performed in this revision.

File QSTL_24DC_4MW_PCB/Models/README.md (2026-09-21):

# Passive 3D model

`R_0603_1608Metric.step` is the generic 1.6 × 0.8 × 0.45 mm resistor from the [official KiCad 3D model library](https://gitlab.com/kicad/libraries/kicad-packages3D/-/blob/master/Resistor_SMD.3dshapes/R_0603_1608Metric.step), retrieved 2026-09-20. It represents the package, not a manufacturer-specific part.

The STEP header credits the 2018 kicadStepUp team and supplies CC BY-SA 4.0 with the KiCad libraries exception for electronic designs. The original header and model are retained without modification. SHA-256: `1875571c326d0d9e96f36b4efeb8094068ef7619f0a449c781caf0b49c2e5861`.

The model is embedded in R1–R6 and `Passives_0603.PcbLib`. Existing capacitor STEP geometry is retained and aligned with the pad axis in the board and `Capacitors_0402.PcbLib`. See `../docs/model_validation.json` for saved-file checks.

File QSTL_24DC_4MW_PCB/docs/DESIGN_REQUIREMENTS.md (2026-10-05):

# User design requirements

Updated 2026-10-05. Later user instructions supersede earlier ones. Read this file before every design-file modification.

## FPC fabrication documentation requested 2026-10-05

- Latest Git delivery request: commit and push the FPC documentation and the requested ZIF-to-two-ZIF-only Altium ZIP. The archive contains only its project, PCB, schematic and required local PCB libraries. Exclude the earlier all-project ZIP and unrelated existing working changes. This supersedes the documentation task's earlier no-commit/no-push scope.
- Terminology clarification: JLCPCB's 2/2 mil line/space at 12 um copper is its published absolute capability limit, not a verified separate orderable process name. Additional line/space charges have not been confirmed. Keep that distinct from the explicitly listed extra charge for the fine two-layer via option.
- Maintain [FPC_DRC_AND_MANUFACTURABILITY.md](FPC_DRC_AND_MANUFACTURABILITY.md) for saved design values, Altium rule coverage, dated JLCPCB FPC limits and unresolved manufacturing issues. Maintain [FPC_ORDER_SPECIFICATION.md](FPC_ORDER_SPECIFICATION.md) for the order settings and fabrication package for the straight FPC, branched FPC and Micro-D adapter. Link both documents from the project READMEs.
- The saved copper target remains 18 um (0.5 oz): one copper layer for the straight cable and two copper layers for each adapter. The user asked about 12 um as an alternative but has not instructed a copper change. Document it as an unimplemented option, including its resistance and mating-thickness implications and its two-/four-layer availability in JLCPCB's published options.
- Distinguish current geometry and stored-rule DRC results from JLCPCB manufacturing compliance. In particular, preserve visibility of the approximately 0.0707105 mm finger gap, special branch drilling, the Micro-D PTH annulus and pending stack/stiffener decisions. Do not label the current files as ready to order, relax rules to claim supplier compliance, or apply the carrier HDI stack/impedance/milling requirements to these separate flex projects.
- This request is for English Markdown documentation. Keep native designs and manufacturing outputs unchanged; do not upload, order, commit or push as part of this documentation-only task.

## Branched FPC and DSUB adapter requested 2026-10-02

- Repository delivery requested 2026-10-03: keep the straight FPC and both adapter projects in the original Git repository and commit/push their designs, local libraries, review images, validation evidence and supporting scripts. They already reside under the repository root, so no relocation is needed. Preserve the documented pending native library/compile checks; Git publication is not fabrication approval. Exclude unrelated CAD work and application-generated working files from this delivery.
- Footprint-link recovery: the first native branch schematic compile reported three missing footprint models. Add component-specific local footprint libraries recovered from the saved PCB pads and contact regions, with explicit schematic model-file links and project membership. Preserve the different A/B/C contact orientations and exact numbered-pad geometry. These libraries now pass independent coordinate round-trip checks; native library loading and recompile remain pending because Altium window activation times out. Preserve the original pre-recovery compile report and do not describe it as a final pass.
- Native DSUB coverlay repair: use one rectangular opening per signal-pin row on each face, with 0.10 mm expansion from the row envelope, instead of unmanufacturably narrow individual coverlay webs. Retain isolated boardlock openings. Accommodate the specified 2.69 mm boardlock drills with a 2.70 mm maximum-hole rule; do not disable the rule. Retain the manufacturer's signal-pad geometry and flag its small PTH annulus for supplier review. This is an editable design, not a JLCPCB fabrication release.
- Native validation repair: recreate the adapter primitives through Altium's PCB API because the offline branch draft produced 51 unrouted reports, 153 antenna reports, 50 hole-spacing reports, 50 mask-sliver reports and a save access violation. Preserve all real violations during repair. Use tented 0.30 mm land / 0.10 mm drill branch vias, consistent with JLCPCB's published two-layer flex extreme capability (extra cost); this restores at least 0.10 mm nominal via-to-trace clearance and increases hole spacing without changing the 70 mm end separation. Supplier process confirmation remains required. Source: https://jlcpcb.com/capabilities/flex-pcb-capabilities
- Latest dimension change: reduce the A-to-B output-tip separation from the provisional 101.6 mm to **70 mm**. Preserve the 420 mm overall draft length and upper output position; move the lower output B upward by 31.6 mm, from Y=318.4 to Y=350 mm. Regenerate routing, coverlay/stiffener boundaries, the saved-file checks and review image. The same-number three-end wiring remains unchanged.
- Confirmed topology: each common-end contact n branches to contact n at both output ends, for all 51 contacts. This is a three-terminal parallel connection for each numbered conductor; do not divide the pin numbers between the outputs. The user explicitly clarified this on 2026-10-02. Keep the Anton reference mapping on the separate DSUB adapter.
- Current native implementation: C is the long Bottom-contact common end; A/B are the two Top-contact outputs. A continuous Top bus joins A and B, and a rounded Bottom bus from C reaches 51 diagonal Top-to-Bottom plated vias in the static junction. Saved via land/drill are 0.30/0.10 mm, superseding the offline draft's 0.35/0.20 mm. Both PCBs were rebuilt with Altium's native API, saved and reopened in a fresh Altium process. Both native DRC reports contain zero violations and rebuilt connection counts are zero. Independent saved-file verification passes 532 branch checks and 87 DSUB checks. Native schematic compilation remains unverified because the Altium validation session stopped responding; independent schematic wire/pin correspondence is verified. This limitation does not waive the remaining native compile check.
- Native mask/paste audit: all contact and through-hole pad paste is disabled. Saved native via mask overrides close apertures on both faces; no explicit via paste-layer primitives exist. The inherited generic via pad-cache booleans do not describe the actual CAM aperture and must not be used alone to infer exposed vias or via paste. Preserve the raw audit output alongside the saved-geometry interpretation. The saved designs have not been released for fabrication: the inherited 0.0707105 mm finger gap, the DSUB footprint's 0.127 mm signal annulus, the fine branch drills and the provisional stack/backing require supplier review.
- Create two additional editable Altium designs from the Molex 15015-0451 contact reconstruction: a ZIF-to-two-ZIF branched flexible board, and a ZIF-to-25-pin-DSUB adapter following the user's sketch. Preserve the original carrier, existing straight cable and read-only reference files.
- Use the same 51-contact, 0.30 mm pitch, 15.60 mm mating width, staggered finger pattern and connector-compatible end thickness. The two right-hand branch contacts are on the illustrated face; the long lower-left contact is on the opposite face, with back stiffeners as drawn. Keep contact numbering/view orientation explicit.
- The sketch requests two copper routing layers and vias at the branch crossover. This is a separate flex-board requirement, not permission to add DC transition vias to the carrier. Use rounded branch transitions and keep vias out of the intended bending zones.
- The sketch marks 20 mm straight end sections, a 10 mm lateral branch dimension and an overall length read as 390 + 30 = 420 mm. Use that overall length provisionally. The right-hand mating-end separation is now explicitly 70 mm, superseding the earlier provisional 101.6 mm. Electrical topology is confirmed by the latest clarification above. Clearly dimension the review so the remaining provisional mechanical interpretation can be reviewed.
- Use the actual saved Anton DSUB-to-ZIF reference netlist for the 25-pin DSUB mapping, including its treatment of odd/even ZIF pins and ground. Do not infer a sequential 1-to-1 mapping.
- Reference inspection: Anton uses NorComp 381-025-112L565 Micro-D. DSUB pins 1..13 map to ZIF 2,6,...50 and pins 14..25 to ZIF 4,8,...48; odd ZIF pins are NC. This new adapter retains reference pin 50; the carrier's separate prohibition on using pin 50 is unaffected. The independent adapter uses a provisional 40 mm length, 31 mm base, manufacturer's 2.69 mm boardlock holes at 24.51 mm pitch and a bonded backing at the DSUB. These are documented design assumptions awaiting any user dimensional correction. Native PCB reopen and DRC pass; native schematic compilation remains pending.
- Keep helper code under script/, verify saved connectivity and mask/coverlay geometry, run native Altium checks where available, and deliver native projects and dimensional review images. Git delivery is authorized by the 2026-10-03 follow-up. No fabrication release or supplier upload is requested.

## SMP density CAD variants requested 2026-10-02

- Latest end-pair correction: the uppermost and lowermost SMP pairs must have the same horizontal centre spacing as well as the existing uniform vertical row pitch. Set both end pairs to X=6.75 / 12.75 mm, giving 6.0 mm horizontal centre spacing and symmetry about X=9.75 mm. This moves only the lower end pair inward by 0.75 mm per connector relative to the last uniform-row version. Retain all seven Y positions and their 6.0 mm pitch. Dimension both end-pair pitches in the review image and verify saved equality and absence of interference. Changes remain CAD-only.
- Latest clarification: tighten and equalize the vertical row spacing of all seven SMP rows, including the uppermost and lowermost added pairs. The user means the Y-direction centre pitch of successive rows, not diagonal centre distances or equal nearest-surface distances. Use a 6.0 mm vertical pitch for the 5.5 mm connector bodies. Set the central row to Y=43.5 mm to avoid SMP-pin intersections with the unchanged Bottom R2/R6 models; the seven row coordinates are Y=25.5, 31.5, 37.5, 43.5, 49.5, 55.5 and 61.5 mm. This reduces the full centre span from 39 to 36 mm and lowers the uppermost pair from Y=62 to 61.5 mm. Preserve the current row X coordinates, connector geometry and mounting height; all SMP occurrences may move in this CAD-only study. Verify uniform saved Y pitch, connector/component clearance and mounting-bore clearance. This supersedes the earlier uneven-row placement and preservation of original SMP Y positions.
- Latest spacing correction: remove connector-to-connector interference in the 14-SMP CAD layout by adjusting longitudinal spacing, and move the upper added pair farther down toward the DSUB end. This supersedes the previous permission to leave SMP intersections in this 14-SMP layout. Retain all 14 connectors, their geometry, mounting height and 2+2+2 arrangement. Prefer longitudinal changes; if the upper pair's horizontal overlap cannot be removed by a common vertical shift, use the minimum symmetric lateral adjustment needed to preserve an aligned pair with a positive gap. Verify all connector pairs using saved B-rep geometry and report the resulting minimum spacing. Preserve the original Altium design, source models and rod assembly.
- Current spacing implementation in the separate CAD study: lower the upper added pair by 2.0 mm to Y=62.0, and spread each outward by 0.5 mm to X=6.75 / 12.75. Retain the central additions and lower additions at their previous positions. Move the lowest original pair SMP5/SMP1 upward by 1.0 mm to approximately Y=28.14, providing clearance to the lower additions without moving them toward the large mounting holes. All other connector positions and heights remain unchanged. These CAD placement changes supersede the earlier instruction to retain all eight original positions, but do not alter the Altium board's pads or drills.
- Latest annotated clarification, now authorized for implementation: add six SMP connectors as 2 + 2 + 2, giving 14 connectors including the existing eight. The indicated locations are an upper pair between the upper mounting holes and upper SMP group, a left/right pair in the central gap between the existing SMP groups, and a lower pair between the lower SMP group and the large mounting holes. The upper and lower added pairs are drawn inward of the existing outer SMP columns; the central additions follow the left/right columns. This supersedes the previous interpretation of additions within every existing horizontal row. Preserve the original eight connectors and create a separate 14-SMP model.
- The sketch contains no exact dimensions. Use symmetric provisional CAD placement centres (mm in the source PCB frame): upper (7.25, 64.00) and (12.25, 64.00); central at the existing left/right column X coordinates and midway between Y=34.34 and 48.84 (approximately Y=41.59); lower (6.00, 23.00) and (13.50, 23.00). These are placement-study choices derived from the sketch, not user-specified dimensions. Preserve the existing SMP geometry, mounting side and height; intersections remain permitted.
- Historical output: two separate mechanical PCB variants were created from the saved DSUB25 PCB CAD with one SMP or two SMPs between each left/right facing pair in all four rows, giving 12 and 16 SMP connectors. Retain those prior outputs separately; they are not the latest annotated six-addition layout.
- This is a CAD-only placement study. Connector intersections are explicitly permitted. Preserve the Altium PCB, schematic, libraries, Gerbers, source STEP and current rod assembly. Do not add electrical pads, routing or substrate holes for the additional connectors.
- Deliver separate STEP models and top/oblique review images. Keep helpers under the repository script folder and record the exact placements and saved-model checks. No Git push is requested.

## Combined rod assembly requested 2026-10-01

- Latest layout request: rearrange all requested PCBs, three gold connectors and the enclosed DSUB device on the existing rods to eliminate placement interference. This supersedes the earlier requirement to preserve the photo reconstruction's PCB positions. Keep the device enclosure/plate/support fastening relationships and use existing rod holes. Preserve source geometry and report any inherited internal fit issues separately from inter-module placement. Retain all requested solid components, suppress illustrative wire/ribbon paths in accordance with the user's no-wire-display preference, and verify the saved assembled geometry before delivery. No Git push is requested.
- Latest enclosure correction: include the existing Bottom/Top_ForFridge device enclosure, lowered central mounting plate, left/right rod supports and supplied standard fasteners with the lower DSUB25 device PCB in the combined rod assembly. Reuse the saved mechanical parts and their mounting relationships; do not leave only a bare PCB. Retain the corrected lower gold-connector depths and omitted rear wires. Check the DSUB replacement against the enclosure/mount and surrounding photo-derived parts, report actual interferences, and regenerate the assembled STEP and review images. Preserve the original source CAD and PCB. No Git push is requested.
- Latest correction: position the two lower gold cylindrical connectors within the rod thickness so that the rods occlude them in a true side view. Remove the illustrative rear wire paths; retain the connector geometry. Preserve the upper connector and the PCB placements. Show a true orthographic side view and a rear detail, and record the revised depth and geometric checks. Any accompanying support-bar adjustment remains photo-estimated placement context, not a verified mounting design.
- Arrange the completed photo-derived DSUB PCB, ZIF PCB, copper-backed filter PCB and three rear gold connectors on the rods according to the supplied photographs. Add the current Altium-derived DSUB25 carrier PCB near the lower rod end.
- Reuse the completed component geometries and the existing rod reference. Preserve the source models and create a separate combined assembly with traceable placement transforms, front/rear/detail views and STEP output.
- The lower carrier is a placement review; any front/rear mounting-face assumption and offset needed to avoid overlap with the filter plate must be recorded. Do not invent verified fasteners, electrical interconnects or production mounting hardware. Check the added carrier against the existing assembly and rod envelope. No Git push is requested.

## DSUB mechanical PCB variant requested 2026-10-01

- Create an additional 3D model of the current saved Altium carrier PCB with a 25-pin DSUB connector replacing its ZIF connector. Use the original Narrow_v4 reference PCB for the DSUB model, position, side and orientation; this is distinct from the photographed electronics reconstruction and the separate Anton adapter.
- Preserve the current PCB outline, cavity, other components and their current placements. Deliver the connector substitution as a separate mechanical model and clearly distinguish it from an electrically rerouted PCB. Do not modify the original Altium PCB, schematic, manufacturing outputs or read-only reference PCB for this model-only request.
- Extract and verify the actual reference connector geometry and placement when available. Provide STEP and preview images, with traceable source hashes and any placement limitations. Keep helpers under the repository script folder. No Git push is requested.

## Photo-based probe electronics models requested 2026-10-01

- Model the photographed DSUB PCB, ZIF PCB, filter PCB above the brown copper plate, and three rear gold cylindrical wire connectors. The user confirmed that the connectors are the two lower units plus the single upper unit connected to the white wires.
- Use the supplied photo collage and its caliper readings, together with available reference CAD/PCB files, as evidence. Keep measured, reference-derived and photo-estimated dimensions distinct. Do not present unreadable measurements or an unconfirmed connector identity as exact.
- Deliver separate 3D parts and an assembled placement review with images. Keep dimensions parameterized so photo estimates can be revised. Preserve the existing carrier PCB, machined split mount, rods and read-only reference files; place this reconstruction in a separate mechanical folder. Helper code belongs in the repository's script folder.
- This request authorizes modeling and local output creation only; it does not request supplier transmission or a new Git push.

## LTspice AC-coupling review requested 2026-09-26

- Latest parameter case: evaluate a 100 nF coupling capacitor and 300 kohm shunt resistor under the same single 100 mV input, and quantify the first 300 us of output decay. Preserve the earlier simulation cases for comparison.
- Previous parameter case: evaluate a 100 nF coupling capacitor and 1 Mohm shunt resistor, with the same single 100 mV input and 300 us decay window. Deliver the voltage-drop graph and retain the previous 10 nF / 300 kohm result for comparison. Use `1Meg` for the resistor value in LTspice.
- Latest follow-up: deliver a graph of the first 300 us after the rising edge and quantify the output voltage drop. Use the saved single-step LTspice data, with time zero at the end of the 1 us rising edge; retain the circuit and non-repeating input.
- Follow-up: run a 300 ms transient simulation, verify the output decay time constant, and deliver the waveform and simulation files. This supersedes the initial circuit-only delivery restriction.
- Prepare and deliver the circuit first, before running the requested voltage-decay measurement: a 10 nF series AC-coupling capacitor followed by a 300 kohm resistor, driven by a 100 mV square wave.
- Initial review interpretation: connect the resistor from the capacitor output to GND and measure OUT relative to GND. Use an ideal voltage source and no additional output load.
- Latest correction: the user explicitly rejected the assumed 50 Hz repetition. Use one 0-to-100 mV rising transition and hold the input high through the 300 ms transient window, with no repeated switching. Retain a 1 ms initial delay and 1 us rise time for the simulation. The single held step is the interpretation communicated to the user for the decay measurement.
- Deliver an editable LTspice schematic in `simulation/LTspice/`. This simulation request does not change the Altium PCB or schematic.

## Language and workspace

- FPC reconstruction implementation (2026-10-02): Molex 15015-0451 sales-drawing geometry uses 101.6 x 15.6 mm, 51 contacts at 0.30 mm pitch, same Top contact face, 3 mm exposed ends and 4 mm back stiffeners. Retain the 0.10/0.30 mm staggered contact neck/finger and 0.20 mm body conductor geometry. Its minimum diagonal gap is about 0.0707107 mm; the 0.0707 mm cable-specific clearance rule is distinct from the carrier's fabrication rules. Record conflicting family-spec width, conductor and stiffener values in the cable README; do not claim proprietary production equivalence. Stiffener extents are fabrication-layer geometry, not native 3D stiffener solids.

- New cable request (2026-10-02): verify Molex 15015-0451, the nominal 102 mm, 51-contact, 0.30 mm pitch Type A FPC, and reproduce its released nominal geometry in a separate editable Altium cable project. Preserve the carrier and read-only references. Reproduce the actual length, staggered same-face contacts, all 51 conductors, reinforcement and specified stack. Resolve catalog rounding using the released drawing; document conflicting or unpublished manufacturing details. Keep helpers under script/, verify saved geometry/connectivity and Altium checks, and deliver native files and a review image. No Git push or fabrication order is requested. This separate cable project is explicitly authorized and is not a replacement carrier revision.

- Write Markdown documents, code comments and technical annotations in English. Use Korean in conversation with the user.
- Edit the original project, PCB and schematic. Do not create a separate V2 project or a final Free Document.
- Keep Python and Altium helper scripts in the repository-root `script/` directory.
- The initial reference PCB and the carrier PCB used to inspect ZIF wiring are read-only.
- Push to Git only when the user requests it.

## PCB fabrication quote requested 2026-09-22

- Regeneration requested 2026-09-24: regenerate the plate-only native DWGs from the current saved 1.6 mm/C1.6 support geometry and deliver a visual drawing preview. Then regenerate PCB Gerbers and separate through/blind drill files from the current even-ZIF 2..48 design, excluding pin 50. Include the Bottom blind-milling layer, existing controlled-impedance stack requirements and fresh saved-design/CAM validation. Preserve the current models and PCB design. This request does not authorize a new order, upload or Git push.

- Export the current original PCB as a complete Gerber and separated drill package, and upload it to the JLCPCB HDI quote interface.
- Quote bare PCBs only, without PCBA or a stencil. Enable controlled impedance for the existing 50-ohm L6 coplanar RF with L5 reference and retain the specified Bottom blind milling pocket.
- Verify the actual L6-L5 blind-via span and its separate laser drill data, including the uploaded layer mapping. Capture the selected ordering options, price and production/shipping lead times. Do not place or pay for a production order.

## Mechanical geometry and placement

- Latest ZIF size correction (2026-09-25): use M1 round/pan-head screws, superseding M1.6. Obtain actual supplied standard hardware, adapt the PCB screw-clearance holes to the confirmed M1 member, and repeat the housing/cable fit check with an explicit hole-to-cable dimensioned top view. Preserve the 19.5 mm board width, electrical routing, direct GND/no-thermal/no-paste mounting treatment and existing six original mounts. Do not silently substitute a larger screw size or custom-model a standard member. Implement using Content Center KS B 1021 M1 x 4, pitch 0.25 mm, head diameter 2.0 mm and head height 0.65 mm. Use 1.2 mm plated clearance drills and 1.6 mm lands at (1.05,1.20) and (18.45,1.20) mm, pitch 17.40 mm. Moving the two end holes 0.55 mm outward gives 0.30 mm nominal cable-to-hole lateral clearance while retaining the board outline; verify the saved dimensions and actual native fit. Implemented and verified: 0.30 mm cable-to-hole clearance per side, 0.627624 mm nominal screw-to-housing distance, no housing/PCB interference, and only permitted head/cable-envelope contact. Saved/reopened DRC: 16 rules, zero violations; independent continuity: 37 nets. Current native review and matching STEP are in Mechanical_Assembly/ZIF_M1_Review. Cable height remains an unverified placement assumption.

- Superseded M1.6 round-head trial (2026-09-25): replace the cylindrical socket-head ISO 4762 review screws with actual supplied standard M1.6 round/pan-head screws. Preserve the approved 1.8 mm PCB holes and existing positions unless the user requests a geometry change. Do not hand-model substitute hardware or add washers. Deliver an enlarged top view that exposes the hole outlines and cable edges, with signed edge-to-edge distances, plus the updated assembled view. Cable-head pressure is permitted, but distinguish it from cable overlap with the drilled holes or screw shanks. This supersedes the earlier ISO 4762 selection below. Implemented with Content Center ISO 7045 H M1.6 x 4 (0.35 mm pitch, 3.2 mm head diameter, 1.3 mm head height). Saved/reopened Inventor finds head-to-housing intersection on both sides. The 15.6 mm cable overlaps each 1.8 mm hole by 0.55 mm in top projection; inside-hole clear width is 14.5 mm. Current positions are unchanged and not interference-free.

- Superseded M1.6 socket-head trial (2026-09-25): MH7/MH8 at (1.60,1.20) and (17.90,1.20) mm, pitch 16.30 mm, plated drill 1.80 mm and land 2.20 mm. Direct GND, no thermal relief or paste, unchanged board outline. Fit review uses unmodified Content Center ISO 4762 M1.6 x 4, pitch 0.35 mm, no washer. Nominal housing gap is only 0.025 mm, less than 0.10 mm radial shank play; housing contact remains possible and tolerance-safe assembly is not confirmed. Cable-head contact is permitted; cable is a dimensional envelope. See Mechanical_Assembly/ZIF_M1p6_Review/README.md.

- Latest PCB mounting request (2026-09-25): add two screw-clearance mechanical holes at the ZIF-side end, at the locations indicated in the user's annotated image. Use direct solid GND connections with no thermal relief, expose the mechanical lands without paste, and preserve the existing six holes and all electrical connectivity. The user subsequently requested M1.5, then explicitly approved changing to M1.6 standard screws after checking the installed ISO 4762 Content Center library. Use M1.6 with 1.8 mm clearance holes and real supplied screw geometry for the fit check. This supersedes the initial M2 implementation. The user confirmed retaining the existing 19.5 mm board width and reducing the hole pitch inward instead of preserving the annotated 17.9 mm pitch. Keep the outline unchanged. Check the matching ZIF cable together with actual supplied M1.6 screw hardware in Autodesk Inventor, including head/cable and connector interference; report the hardware and cable assumptions and any collision. The user explicitly permits the screw heads to press against the cable; do not classify that intended contact alone as a rejection. Continue to check the connector housing, PCB signal copper, hole-edge margins and fastener seating. Then regenerate affected fabrication outputs and show the result.

- Latest rod-fastener change (2026-09-24): replace the eight rod-mounting screws with actual round/button-head M3x8 screws from the installed Autodesk Inventor Content Center. Retain the standard 0.5 mm pitch, existing bearing planes and fastening direction through the 1.6 mm support flanges into the rod threads. Preserve the two device screws, eight countersunk deck screws and all fabricated geometry; do not add washers. Check the supplied head envelope, bearing contact and cylinder interference, and show the updated assembly.

- Latest 1.6 mm flange correction (2026-09-24): reduce both outer rod-contact flanges from 2 mm to 1.6 mm, retaining the 45-degree full-thickness outer bevel (now C1.6). After confirming that the reference rods already have M3 through threads, the user cancelled threading the support flanges. Keep their eight holes as plain 3.4 mm M3 clearance holes and retain fastening through the support into the existing rod threads; do not add flange threads, reverse the joint or alter the original rods. Preserve the central deck, boss, rod mating plane and device placement. Re-measure the PCB pocket-floor +0.300 mm cavity-side reference point against the cylinder axis using saved assembly transforms, and deliver a native axial top view. Update native CAD, STEP and affected DWGs. Retain the supplied standard hardware and report actual seating, tip projection and remaining interference.

- Latest support-end change (2026-09-24): the user's section sketch marks the outer rod-contact support flange, not the central deck. Reduce both marked end flanges from 4 mm to 2 mm and bevel their outer ends with a full-thickness C2 x 45-degree chamfer as drawn. Retain the central deck/boss, rod-contact datum and device/pocket alignment. Update affected native models, assembly references, STEP exports and fabrication/assembly DWGs. Check flange screw seating, real standard screw engagement and the bevel against mounting holes; do not introduce washers or handmade hardware.

- Standard hardware requirement: use the actual M3 fasteners supplied by Autodesk Inventor Content Center. Do not substitute custom simplified screw shapes. Replace the custom M3 hardware in the current split-mount assembly with the appropriate supplied standard families/members, retaining the normal 0.5 mm pitch and checking real head envelopes, clearances and engagement. Preserve the newly requested device relief grooves.
- Implemented hardware: eight DIN 7991 M3x10 deck screws, eight ISO 7380-1 M3x8 button-head rod screws and two ISO 4762 M3x8 device screws from the installed Inventor 2027 Content Center, with unmodified source member files and M3x0.5-6g external thread features. Enlarge the eight 90-degree deck countersinks to 6.6 mm for the actual 0.2 mm head rim and 0.1 mm recessed head face. Preserve internal M3x0.5-6H threads. Cosmetic thread-cylinder overlap is acceptable only within the documented tapped depth and nominal thread diameter. Legacy illustrative fastener builders are historical and must not overwrite this standard-hardware state.
- Latest user correction: do not introduce device washers as an unsolicited clearance fix. Remove the added washers and restore the original screw bearing planes. Keep the reference device unchanged. Report the actual local under-head fillet/slot intersection separately; do not hide it, reshape the standard screw, or add other hardware to claim clearance.

- Latest mounting-interface change: machine two 0.5 mm deep relief grooves in the central plate at the device mounting lips indicated in the user's end-view image. Measure the actual device screw-mounting lip thickness from the saved CAD; groove width must equal that thickness plus 0.3 mm total clearance. Preserve the device, the existing mounting datum and thread locations, and update the affected native model, STEP, fabrication/assembly DWGs and delivery package. Keep comments and drawing annotations in English.
- Implemented relief geometry: measured lip thickness 3.039840616900516 mm; each groove is 3.339840616900516 mm wide, 72 mm long and 0.5 mm deep, with R0.5 closed-end corners. Grooves run along both boss sides at local Y=4..76 mm, Z=3.5..4 mm. The 0.3 mm width allowance extends outward from the unchanged boss contact faces. Preserve the existing carrier placement and M3 axes.

- Latest drawing correction: remove the manually typed BILL OF MATERIALS and ASSEMBLY SEQUENCE blocks shown by the user. Follow the native drawings and presentation in `C:/JeonghyunPark/Workspace/QSTL_M12C_BNC/Enclosure3` for assembly documentation. Show the three-part plate assembly with clear exploded geometry, alignment trails/fastening direction and assembled views instead of prose blocks. Deliver native, editable DWG sheets with correctly sized paper and a saved fit-to-sheet view. Preserve all reference files and fabrication geometry.

- Deliver the split-mount manufacturing and assembly drawings in DWG format. Inspect the user's existing mechanical drawings first and follow their sheet, title-block, projection, dimensioning and annotation conventions. A PDF-only package does not satisfy this requirement. Preserve source/reference drawings and model geometry.

- Limit this DWG package to fabrication of the central plate/boss, left support and right support, plus their screw-fastened three-part assembly. Exclude the cylinder, rod/device installation and sleeve-fit drawings. The three-part exploded/assembled joint drawing remains required.

- Omit the general NOTES block shown by the user, including supplier grade/temper declarations, proposed RFQ tolerances/roughness, release/confirmation text, quantity/TBD statements and STEP-governs boilerplate. Keep material and surface treatment in the title block, dimensional/thread callouts on views, and the actual plate assembly instructions. Do not move the removed notes elsewhere in the drawing.

- Material for the three machined split-mount parts (central plate/boss and both rod supports) is oxygen-free copper (OFC), with no surface treatment or coating. Record the supplier's exact OFC grade and material certificate; do not invent an approved alloy grade, temper or thermal-performance specification. Machined surface roughness remains a separate drawing requirement from surface treatment.

- Prepare a CNC drawing package for the split lowered variant: dimensioned drawings for the central plate with integral boss and both rod supports, plus an exploded assembly drawing, hardware schedule and assembly sequence. Use the saved CAD geometry as the dimensional source. Drawings and notes must be in English. Preserve the models while preparing the drawings; explicitly identify unresolved material, finish, quantities, production tolerances, blind-thread tooling and existing sleeve envelope clashes before manufacturing release. Include STEP files with the drawing package. No ordering, supplier contact or Git push is authorized by this drawing request.

- Split the lowered variant at the deck-to-support interface shown by the user. Use three separately machinable parts: the central deck with its integral device boss, and separate left/right rod supports. Join the central deck to the supports with screws inserted from the outside deck face. Retain the 8.5 mm drop and the aligned pocket reference point. Use 6 mm wide connecting walls to accommodate two rows of M3 assembly screws without changing the 6 x 80 mm rod contact footprints. The initial detail uses four M3 x 10 countersunk screws per support, 20 mm pitch, with heads recessed to preserve the cylindrical envelope. Archive the superseded monolithic lowered adapter; preserve the original flat version unchanged. Verify separate solids, mating faces, screw engagement, saved thread metadata and the assembled centre alignment. Final machining radii and tolerances remain unspecified.

- Add a separate stepped mounting-plate variant while preserving the existing flat plate and its assembly unchanged. Lower the central deck, mounting boss, carrier and device fasteners by 8.5 mm relative to the current arrangement, as in the user's end-view sketch. Keep both rod-contact flanges and rod fasteners at their current locations. Preserve the 80 mm contact length, 4 mm plate/web thickness, 6 mm boss height and bilateral five-hole M3 x 0.5 - 6H rows at 16 mm pitch. Align the point 0.300 mm from the PCB pocket floor toward the cavity opening with the sleeve axis, including the measured +0.139127461912 mm lateral correction of the boss/carrier/device screws. The axis remains X=25.5 mm, Z=3 mm. This additional variant supersedes the earlier instruction to retain only one mechanical arrangement; both requested versions must remain available. Verify actual saved placements, connected solid geometry, contact/interference and centre alignment. Do not change the original holder, PCB, rods or sleeve.

- Preserve the reference 19.5 x 67.9 mm outline, all eight SMP positions and six mechanical mounting holes.
- ZIF and SMP are on Top. QD and all R/C components are on Bottom.
- Preserve the requested QD orientation and pad numbering 1-24.
- The central QD cavity remains 4.3 x 4.3 mm. The latest user correction requires moving the QD pads outward by 0.2 mm, making the square defined by inward-facing pad ends 4.7 x 4.7 mm. Preserve the 1.0 x 0.5 mm pad sizes and 0.7 mm pitch along each row; cavity-to-pad clearance is 0.2 mm.
- Move at most one pad from each side to the upper edge, only if necessary to resolve a corner collision. Current upper pads are 1 and 24.
- Use 0603 resistors and 0402 capacitors. Component rotations must be multiples of 45 degrees.
- Place all six R/C pairs inward as shown by the user. The lower R1/C1 and R5/C5 groups are rotated 90 degrees from the previous arrangement.
- Align capacitor 3D models with their pad axes and use a proper 0603 resistor package model.

## RF and DC connectivity

- RF QD pads are 1, 6, 9, 12, 18 and 24. Preserve the physical positions of the initial four RF channels; QD12 and QD18 are additional RF connections.
- Current mapping: SMP1 to QD9, SMP2 to QD6, SMP3 to QD1, SMP4 to QD24, SMP5 to QD12, SMP6 to QD18. SMP7/8 centre pins are NC.
- Each RF channel has a series capacitor and DC bias resistor. The RF path must pass through the resistor RF-side pad centre without a separate resistor branch stub.
- Use via-in-pad for the 18 QD DC pads and the DC-feeding bias-resistor pads. QD RF pads 1/6/9/12/18/24 connect entirely on Bottom and must have no vias; this supersedes the earlier all-QD-pad via requirement. R1-R6 must have exactly one via each, at DC pad 2. RF pad 1 connects entirely on Bottom and must have no via; do not add a through via to a same-layer RF junction. This explicitly supersedes the former two-vias-per-resistor implementation. RF series capacitors remain entirely on Bottom: remove their redundant through vias to avoid RF stubs. Retain their normal SMD pads and paste. Place R/C close together, with C naturally aligned to the RF path.
- Connect the 18 DC-only QD pads and six RF bias resistors to the 24 even ZIF contacts 2, 4, 6, ..., 48 only, matching Anton's adapter contact convention. Pin 50 is explicitly unused; all odd contacts remain NC. Preserve the actual footprint contact numbering and synchronize the schematic, QD library labels and PCB. This supersedes the previous 1-12 and 15-26 assignment.
- Resolve crossings by changing ZIF assignments in the schematic and PCB together. Each DC net must complete its route on one internal signal layer. Do not add standalone DC layer-transition vias.
- Current even-contact bias assignments: R1=48, R2=46, R3=42, R4=8, R5=4, R6=2. All six resistor DC pads remain connected and all RF pad assignments remain unchanged. The 2026-09-22 Gerber/HDI quote package predates this DC remap and must be regenerated before production.

## Routing and layer stack

- Latest DC pour clearance correction (2026-09-24): increase the L2/L4 GND-pour clearance to non-GND copper from 0.15 mm to 0.20 mm. Persist a dedicated native Altium clearance rule, repour those two polygons, and verify saved/reopened geometry, connectivity and DRC before refreshing images and fabrication outputs. Preserve trace positions, trace-to-trace rules, RF geometry, all other ground layers, masks, pin mapping and vias. The default 0.15 mm non-RF clearance below remains applicable outside this targeted pour rule.

- DC copper-pour request (2026-09-24, confirmed): add GND copper pour around the existing DC tracks on L2 and L4, and send images of both layers before regenerating Gerbers. Preserve the even-contact assignment, single internal layer per net, existing clearances, QD exclusions and blind-via span. Remove unconnected copper islands; do not expand the individual DC signal nets or add DC transition vias.

- From the QD side: RF / GND / DC / GND / DC / GND. Physical layers: L6 RF, L5 GND, L4 DC, L3 GND, L2 DC, L1 GND.
- RF is on Bottom with QD and R/C. RF and DC must not cross the QD interior.
- Straight tracks may only be horizontal, vertical or 45 degrees. RF corners must be tangent curves. Each DC corner must turn at most 45 degrees; do not use a single sharp 90-degree corner.
- Use XY overlap between the two independent DC layers. Preserve clearance to other nets on the same layer and to through-hole pads/vias on every layer.
- Gather DC routes near the board centre. Do not pull them toward large GND holes. Preserve clearance and minimize bends.
- Current DC width is 0.125 mm and Top ZIF escapes are 0.15 mm. RF width changes to 0.11 mm with a 0.2 mm coplanar GND gap, following the supplied JLCPCB 50-ohm HDI calculation. Default non-RF clearance stays 0.15 mm. Central DC bus pitch is 0.6 mm.
- Preserve short RF centreline routes and tangent arcs. The user deferred 1 ps delay matching. Specify 50 ohms as the controlled-impedance target; calculator geometry is not a measured guarantee for connector, component or wire-bond transitions.
- Use the supplied 6-layer 1078 HDI stack: copper 0.035/0.0152/0.0152/0.0152/0.0152/0.035 mm, and dielectric gaps 0.0784/0.55/0.2008/0.55/0.0784 mm. Match L6/L5 to the symmetric L1/L2 calculator geometry. Use the current calculator's actual stack code in fabrication notes.

## Solder mask, paste mask and QD ground exclusion

- The request to remove the green coating means solder-mask removal. Use explicit Top/Bottom Solder openings on general board areas, retaining mask at soldering sites and RF routes.
- QD is a wire-bonding area. Remove Bottom solder mask across its pad field and central cavity. Retain solder-control mask around SMD R/C, ZIF contacts/fanout, SMP signal/ground pins, and retain mask on RF away from the QD bond-pad field. The Top reverse side retains its previous via tenting.
- Preserve mask over RF tracks and tangent curves, including a margin from the RF copper edge. Initial implementation uses a 0.25 mm protected margin. Do not change RF copper to achieve a visual mask change.
- Latest explicit follow-ups: remove every via-specific Top/Bottom Paste aperture and all paste apertures on mechanical mounting pads and SMP pads. Normal SMD component-pad paste openings must remain. This overrides the earlier request for paste apertures on every via.
- The user clarified that removing paste on mechanical parts and SMP does not mean removing their solder mask. Retain SMP solder-control masks; the later explicit mounting-hole request now removes mounting masks.
- Retain via tenting in protected soldering areas. Solder-mask coating and paste-mask stencil apertures are separate features and must be audited separately.
- Remove GND within the QD inner-end square on every copper layer except Top. The updated inner pad-end boundary is x=7.4-12.1 mm and y=40.15-44.85 mm, centred at (9.75,42.5) mm.
- Keep Top GND within that square and retain layer-specific polygon-pour cutouts on L2/L3/L4/L5/L6. The latest user request authorizes a non-through milled pocket from the QD/Bottom face, with a 4.3 x 4.3 mm outer envelope and 1.2 mm depth. This supersedes the earlier instruction not to mill the substrate. Do not create a through-board cutout. Move the QD pads outward as specified above and reconnect their existing via-in-pad fanouts.
- The pocket envelope is x=7.6-11.9 mm, y=40.35-44.65 mm, inset 0.2 mm from each 4.7 mm pad-end boundary. The latest user correction preserves the 4.3 mm QD cavity and moves the pads, superseding the earlier proposal to shrink the cavity to 3.9 mm. Use rounded internal CNC corners and state the cutter radius in the drawing.
- JLCPCB requires a separate Bottom Blind Slots Gerber, side/depth/metallization order fields, a location/section drawing and an order remark naming the layer. Specify a non-plated cavity. Verify the remaining substrate and nearest copper clearance; no production order is authorized.
- Recheck these mask and GND conditions after every subsequent layout or polygon modification.

## Vias and validation

- Extend shield fences around R1-R6 and C1-C6. Treat each two-pad convex hull (including the inter-pad bridge/body area) as a forbidden region for shield-via lands; surround the outside instead of cutting between the pads.
- Active SMP rings must use equal angular increments and symmetric RF exits. Choose an equal-angle grid from the hole-edge clearance radius and nominal 0.40 mm chord pitch. Keep the RF exit gap symmetric; do not retain an obsolete fixed via count when the radius changes.
- Latest mechanical-hole instruction supersedes the earlier protected mounting mask: expose all six mounting lands and their surrounding ring on both solder-mask layers. Connect these GND mounting pads directly to every GND polygon with no thermal spokes/voids. SMP solder-control masks and normal SMD paste remain unchanged; mounting paste remains disabled.

- Add GND shield vias along both sides of RF routes, with nominal 0.15 mm copper-land-edge spacing, equivalent to 0.40 mm centre spacing for the retained 0.25 mm lands. Use chord spacing at curves/rings; larger local gaps are allowed only to preserve pad/hole and RF-exit clearance. This supersedes the previous 2 mm pitch. The latest correction measures three RF widths from the RF copper edge to the laser-drill hole edge, not to the via land. For 0.11 mm RF and 0.10 mm holes, the centre offset is 0.435 mm; the 0.25 mm land edge is 0.255 mm from RF copper.
- Shield vias connect L6/Bottom RF coplanar GND to adjacent L5 GND only. Use laser blind microvias, nominal 0.1 mm drill and 0.25 mm land, with solid connections and no thermal spokes or paste apertures. They must not reach L4/L2 DC layers. Continue the fence inside each active SMP footprint as a ring around its signal centre, leaving the RF escape corridor clear.
- Preserve via-in-pad; component pad mask openings remain distinct from via-specific tent flags. Via-specific paste apertures must be absent.
- Avoid unintended component, pad and routing overlaps. Intentional same-net joints and via-in-pad are allowed.
- Keep PCB, schematic and library pin definitions consistent. Save/reopen and check DRC and retained connection counts. Independently verify actual copper connectivity on all layers.
- Verify solder-mask openings against protected RF/soldering geometry, normal SMD paste preservation, absence of via-specific paste, and GND exclusion on all non-Top layers with Top GND retained.

## Latest placement and rectangular mask refinement

- Centre the device on the plate's longitudinal bisecting plane X=25.5 mm. After its end-for-end reversal, move the device and mating boss together by +2.088496738338 mm in X. The boss's local X minimum becomes 19.794248369169 mm; its width remains 13.5 mm. The device centre is defined by the midpoint of the complete carrier's X bounds. Preserve all hole pitches and the inward-facing mounting arrangement.

- Latest correction supersedes the previous whole-group rotation: attach the plate to the opposite rod face while keeping its boss directed inward between the two rods. The plate occupies Z=-4 to 0 mm; rods remain Z=0 to 6 mm and the boss occupies Z=0 to 6 mm. Keep the screenshot-confirmed device orientation with ZIF uppermost (180-degree in-plane turn). Move this device/boss group inward without turning the boss outward. Rod screws enter from Z=-4 mm toward +Z. Keep only this corrected arrangement as the final assembly.

- Shorten the mounting plate to approximately the complete device length. The unchanged carrier spans 79.43999922 mm along the rods; use an 80 mm plate from assembly Y=135 to 215 mm. Retain its 51 mm width, 4 mm thickness and 13.5 x 6 mm boss cross section. The boss length becomes 72 mm. Keep the existing carrier and occupied screw positions; retain five M3 x 0.5 - 6H holes per boss side at 16 mm pitch (Y=144.82802366515844 through 208.82802366515844 mm) and four rod fasteners per rod at Y=140,160,180,200 mm. This supersedes the longer plate, eight-hole boss rows and 16 rod fasteners. Reversal reviews use the shortened plate.

- Final orientation is the screenshot explicitly confirmed by the user: ZIF is at the upper end and the carrier is rotated 180 degrees in the plate plane, then the complete plate/carrier/fastener group is mounted on the opposite rod face. The confirmed open document was `Orientation_Review/Both_reversed.iam`. Promote this exact placement to the main assembly and retain only this final result. The device uses the opposite threaded boss face at reference Y=160.82802366515844 and 176.82802366515844 mm. The full group reversal is 180 degrees about the rod-axis line X=25.5, Z=3 mm. Preserve rod and sleeve positions, the 80 mm plate and all source part geometry. Archive intermediate alternatives in the script temporary folder.

- Add matching threaded rows to both opposite side faces of the raised device-mounting boss. Each side has eight right-hand M3 x 0.5 - 6H threads at the same 16 mm pitch and aligned Y/Z centres, for 16 threads total. Retain 6 mm modeled bore/thread depth per side and the 13.5 mm boss width, leaving a 1.5 mm solid web between opposed bores. Preserve the existing two device screws, all assembly placements and the sleeve.

- Add a separate open-ended cylindrical sleeve around the H frame: inner diameter 51 mm, outer diameter 54 mm, with its axis through the midpoint of the two rod centre lines. Current frame rod centres are (X,Z)=(3,3) and (48,3) mm, so the sleeve axis is X=25.5 mm, Z=3 mm, parallel to Y. Use 360 mm length matching the rods unless the user specifies another length. Preserve these requested diameters and the existing geometry; measure and report actual intersections rather than silently resizing the sleeve or other parts. Add the sleeve to the current mechanical assembly and keep the standalone part editable.

- Match the Coldfinger-v2 lower device-mounting hole row on the indicated raised boss face: 16 mm centre spacing, right-hand M3 x 0.5 - 6H internal threads. Extend the current two device mounting holes into eight positions at local Y=17.82802366515844 + 16*n mm (n=0..7), retaining the existing two screw locations and unchanged carrier placement. Preserve the solid plate and boss. Record real Inventor thread features, not only plain bores. The reference drawing has an inconsistent 4 mm drill / 6 mm thread depth callout; retain the existing 6 mm model depth rather than copying the contradictory 4 mm pilot depth.

- Latest top-view correction and annotated follow-up: fill both empty longitudinal openings completely, making one solid plate across the rods. The device screw-mounting face must project integrally above this plate. Put this raised boss under the holder body on the inside of its existing flange, matching the PPT end-view silhouette. The follow-up clarifies the missing plate material and projecting mounting face; retain the existing device slots rather than inventing another hole pattern. Preserve the original holder and maximize rod contact. This supersedes the open-frame adapter and the previous boss outside the holder footprint.

- The user identified `assembly_coldfinger_v2.SLDASM` as the combined reference. Its imported assembly confirms that Top_ForFridge mounts by its existing side slots to the narrow Coldfinger-v2 support. Use this side-clamp interface, with the device body exposed. The current concept uses 150 x 6 mm continuous contact on each rod in the free middle bay and two M3 device screws at the existing 16 mm slot pitch. All new thicknesses and fastener details remain provisional; preserve the existing device slots and rod holes.

- Build the user's sketched rod-to-holder adapter as a separate mechanical part and review assembly. Latest correction: do not cover or surround the original device/holder with a broad saddle. Use the hanging and screw-tightened attachment method demonstrated in the read-only ColdFinger DilFridge mechanical v2 reference. Inspect that mechanism before redesigning the adapter. Maximize contact with both rods using extended contact surfaces and distributed clamping, while keeping the device body exposed. Retain the carrier, PCB, and H-frame source models unchanged. Match the rod M3 pattern and use the existing device mounting feature; record provisional dimensions as editable parameters. Do not add or move holes in the reference holder. This supersedes the previous broad raised-saddle adapter.

- Build a separate simplified H-shaped probe support frame from the supplied SO01373.10-Probe-R01.pdf: two copper rods, 360 mm long, 6 mm wide, with 45 mm centre spacing (51 mm overall width and 39 mm clear gap), 33 M3 through-thread locations per rod at 10 mm pitch starting 30 mm below the top. Exclude the upper anchor, lower mechanism and enclosing tube. Use two crossbars at approximately 110 and 270 mm below the top, with estimated 8 mm height. Rod/crossbar front-to-back depth is not dimensioned: use an explicitly provisional 6 mm and retain editable parameters. Model M3 threads as simplified cylindrical openings; do not invent unshown fastener details. Preserve the existing PCB/carrier assembly and save the frame separately in the repository.

- Export the current PCB as a simplified mechanical 3D model for an Inventor assembly. Preserve board outline, thickness, mounting holes, QD pocket, component positions and sides, and component envelope dimensions/heights. Simplify resistor and capacitor models but retain their physical sizes and heights. Fit the SMP/Top PCB face to Bottom.SLDPRT, and the opposite QD/Bottom PCB face to Top_ForFridge.SLDPRT from the read-only Narrow_V3_24DC_8MW reference folder. The latest user clarification selects Top_ForFridge instead of Top.SLDPRT and accepts the SMP overlaps for this assembly pass. Save the derived assembly and models in the working repository; do not overwrite the reference SolidWorks files.

- Latest lower-pair refinement: move R1/C1 and R5/C5 toward X=9.75 mm so that each pair centre is at 70% of its previous distance from this board centreline. Define each pair centre by the union of its pad envelopes. Move each pair rigidly in X, preserving Y, spacing and rotations; reconnect RF and DC and rebuild masks and shielding. This is an additional move from the saved revision immediately before this request.
- Move upper R3/C3 and R4/C4 upward by 2.0 mm, away from the QD bond pads. Move both lower R1/C1 and R5/C5 upward by 1.0 mm, as confirmed by the user. Additionally move R1/C1 inward by 0.35 mm. Preserve pair spacing and rotations; reconnect RF/DC without adding transition vias.
- Increase the retained solder-control margin around each R/C group from 0.30 to 0.90 mm. Use exact axis-aligned group rectangles, not rounded convex-hull patches. Preserve normal SMD pad openings and paste, RF coverage and the unmasked QD field.
- Cover the complete Bottom ZIF fanout-via array with a rectangular solder-mask area, extending 0.40 mm beyond its via lands.

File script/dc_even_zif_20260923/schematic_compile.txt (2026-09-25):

PROJECT=C:\JeonghyunPark\Workspace\QSTL_24DC_4MW_PCB\QSTL_24DC_4MW_PCB\QSTL_24DC_4MW_PCB.PrjPcb
COMPILE_START
COMPILE_RESULT=False
VIOLATION_COUNT=0
NET_COUNT=68
NET=ZIF48|PINS=2
PIN=J1-48
PIN=R1-2
NET=ZIF46|PINS=2
PIN=J1-46
PIN=R2-2
NET=ZIF44|PINS=2
PIN=J1-44
PIN=Q1-2
NET=ZIF42|PINS=2
PIN=J1-42
PIN=R3-2
NET=ZIF40|PINS=2
PIN=J1-40
PIN=Q1-3
NET=ZIF38|PINS=2
PIN=J1-38
PIN=Q1-14
NET=ZIF36|PINS=2
PIN=J1-36
PIN=Q1-4
NET=ZIF34|PINS=2
PIN=J1-34
PIN=Q1-15
NET=ZIF32|PINS=2
PIN=J1-32
PIN=Q1-5
NET=ZIF30|PINS=2
PIN=J1-30
PIN=Q1-16
NET=ZIF28|PINS=2
PIN=J1-28
PIN=Q1-7
NET=ZIF26|PINS=2
PIN=J1-26
PIN=Q1-17
NET=ZIF24|PINS=2
PIN=J1-24
PIN=Q1-8
NET=ZIF22|PINS=2
PIN=J1-22
PIN=Q1-19
NET=ZIF20|PINS=2
PIN=J1-20
PIN=Q1-10
NET=ZIF18|PINS=2
PIN=J1-18
PIN=Q1-20
NET=ZIF16|PINS=2
PIN=J1-16
PIN=Q1-11
NET=ZIF14|PINS=2
PIN=J1-14
PIN=Q1-21
NET=ZIF12|PINS=2
PIN=J1-12
PIN=Q1-13
NET=ZIF10|PINS=2
PIN=J1-10
PIN=Q1-22
NET=ZIF08|PINS=2
PIN=J1-8
PIN=R4-2
NET=ZIF06|PINS=2
PIN=J1-6
PIN=Q1-23
NET=ZIF04|PINS=2
PIN=J1-4
PIN=R5-2
NET=ZIF02|PINS=2
PIN=J1-2
PIN=R6-2
NET=S6|PINS=2
PIN=C6-1
PIN=SMP6-1
NET=S5|PINS=2
PIN=C5-1
PIN=SMP5-1
NET=S4|PINS=2
PIN=C4-1
PIN=SMP4-1
NET=S3|PINS=2
PIN=C3-1
PIN=SMP3-1
NET=S2|PINS=2
PIN=C2-1
PIN=SMP2-1
NET=S1|PINS=2
PIN=C1-1
PIN=SMP1-1
NET=NetSMP8_1|PINS=1
PIN=SMP8-1
NET=NetSMP7_1|PINS=1
PIN=SMP7-1
NET=NetJ1_53|PINS=1
PIN=J1-53
NET=NetJ1_52|PINS=1
PIN=J1-52
NET=NetJ1_51|PINS=1
PIN=J1-51
NET=NetJ1_50|PINS=1
PIN=J1-50
NET=NetJ1_49|PINS=1
PIN=J1-49
NET=NetJ1_47|PINS=1
PIN=J1-47
NET=NetJ1_45|PINS=1
PIN=J1-45
NET=NetJ1_43|PINS=1
PIN=J1-43
NET=NetJ1_41|PINS=1
PIN=J1-41
NET=NetJ1_39|PINS=1
PIN=J1-39
NET=NetJ1_37|PINS=1
PIN=J1-37
NET=NetJ1_35|PINS=1
PIN=J1-35
NET=NetJ1_33|PINS=1
PIN=J1-33
NET=NetJ1_31|PINS=1
PIN=J1-31
NET=NetJ1_29|PINS=1
PIN=J1-29
NET=NetJ1_27|PINS=1
PIN=J1-27
NET=NetJ1_25|PINS=1
PIN=J1-25
NET=NetJ1_23|PINS=1
PIN=J1-23
NET=NetJ1_21|PINS=1
PIN=J1-21
NET=NetJ1_19|PINS=1
PIN=J1-19
NET=NetJ1_17|PINS=1
PIN=J1-17
NET=NetJ1_15|PINS=1
PIN=J1-15
NET=NetJ1_13|PINS=1
PIN=J1-13
NET=NetJ1_11|PINS=1
PIN=J1-11
NET=NetJ1_9|PINS=1
PIN=J1-9
NET=NetJ1_7|PINS=1
PIN=J1-7
NET=NetJ1_5|PINS=1
PIN=J1-5
NET=NetJ1_3|PINS=1
PIN=J1-3
NET=NetJ1_1|PINS=1
PIN=J1-1
NET=MW6|PINS=3
PIN=C6-2
PIN=Q1-18
PIN=R6-1
NET=MW5|PINS=3
PIN=C5-2
PIN=Q1-12
PIN=R5-1
NET=MW4|PINS=3
PIN=C4-2
PIN=Q1-24
PIN=R4-1
NET=MW3|PINS=3
PIN=C3-2
PIN=Q1-1
PIN=R3-1
NET=MW2|PINS=3
PIN=C2-2
PIN=Q1-6
PIN=R2-1
NET=MW1|PINS=3
PIN=C1-2
PIN=Q1-9
PIN=R1-1
NET=GND|PINS=32
PIN=SMP1-2
PIN=SMP1-3
PIN=SMP1-4
PIN=SMP1-5
PIN=SMP2-2
PIN=SMP2-3
PIN=SMP2-4
PIN=SMP2-5
PIN=SMP3-2
PIN=SMP3-3
PIN=SMP3-4
PIN=SMP3-5
PIN=SMP4-2
PIN=SMP4-3
PIN=SMP4-4
PIN=SMP4-5
PIN=SMP5-2
PIN=SMP5-3
PIN=SMP5-4
PIN=SMP5-5
PIN=SMP6-2
PIN=SMP6-3
PIN=SMP6-4
PIN=SMP6-5
PIN=SMP7-2
PIN=SMP7-3
PIN=SMP7-4
PIN=SMP7-5
PIN=SMP8-2
PIN=SMP8-3
PIN=SMP8-4
PIN=SMP8-5
COMPLETE

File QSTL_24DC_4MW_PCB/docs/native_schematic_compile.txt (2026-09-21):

PROJECT=C:\JeonghyunPark\Workspace\QSTL_24DC_4MW_PCB\QSTL_24DC_4MW_PCB\QSTL_24DC_4MW_PCB.PrjPcb
COMPILE_START
COMPILE_RESULT=False
VIOLATION_COUNT=0
NET_COUNT=68
NET=ZIF26|PINS=2
PIN=J1-26
PIN=R4-2
NET=ZIF25|PINS=2
PIN=J1-25
PIN=R2-2
NET=ZIF24|PINS=2
PIN=J1-24
PIN=Q1-14
NET=ZIF23|PINS=2
PIN=J1-23
PIN=R3-2
NET=ZIF22|PINS=2
PIN=J1-22
PIN=Q1-15
NET=ZIF21|PINS=2
PIN=J1-21
PIN=R1-2
NET=ZIF20|PINS=2
PIN=J1-20
PIN=Q1-16
NET=ZIF19|PINS=2
PIN=J1-19
PIN=Q1-2
NET=ZIF18|PINS=2
PIN=J1-18
PIN=Q1-17
NET=ZIF17|PINS=2
PIN=J1-17
PIN=Q1-3
NET=ZIF16|PINS=2
PIN=J1-16
PIN=Q1-19
NET=ZIF15|PINS=2
PIN=J1-15
PIN=Q1-4
NET=ZIF12|PINS=2
PIN=J1-12
PIN=Q1-20
NET=ZIF11|PINS=2
PIN=J1-11
PIN=Q1-5
NET=ZIF10|PINS=2
PIN=J1-10
PIN=Q1-21
NET=ZIF09|PINS=2
PIN=J1-9
PIN=Q1-7
NET=ZIF08|PINS=2
PIN=J1-8
PIN=Q1-22
NET=ZIF07|PINS=2
PIN=J1-7
PIN=Q1-8
NET=ZIF06|PINS=2
PIN=J1-6
PIN=Q1-23
NET=ZIF05|PINS=2
PIN=J1-5
PIN=Q1-10
NET=ZIF04|PINS=2
PIN=J1-4
PIN=R6-2
NET=ZIF03|PINS=2
PIN=J1-3
PIN=Q1-11
NET=ZIF02|PINS=2
PIN=J1-2
PIN=R5-2
NET=ZIF01|PINS=2
PIN=J1-1
PIN=Q1-13
NET=S6|PINS=2
PIN=C6-1
PIN=SMP6-1
NET=S5|PINS=2
PIN=C5-1
PIN=SMP5-1
NET=S4|PINS=2
PIN=C4-1
PIN=SMP4-1
NET=S3|PINS=2
PIN=C3-1
PIN=SMP3-1
NET=S2|PINS=2
PIN=C2-1
PIN=SMP2-1
NET=S1|PINS=2
PIN=C1-1
PIN=SMP1-1
NET=NetSMP8_1|PINS=1
PIN=SMP8-1
NET=NetSMP7_1|PINS=1
PIN=SMP7-1
NET=NetJ1_53|PINS=1
PIN=J1-53
NET=NetJ1_52|PINS=1
PIN=J1-52
NET=NetJ1_51|PINS=1
PIN=J1-51
NET=NetJ1_50|PINS=1
PIN=J1-50
NET=NetJ1_49|PINS=1
PIN=J1-49
NET=NetJ1_48|PINS=1
PIN=J1-48
NET=NetJ1_47|PINS=1
PIN=J1-47
NET=NetJ1_46|PINS=1
PIN=J1-46
NET=NetJ1_45|PINS=1
PIN=J1-45
NET=NetJ1_44|PINS=1
PIN=J1-44
NET=NetJ1_43|PINS=1
PIN=J1-43
NET=NetJ1_42|PINS=1
PIN=J1-42
NET=NetJ1_41|PINS=1
PIN=J1-41
NET=NetJ1_40|PINS=1
PIN=J1-40
NET=NetJ1_39|PINS=1
PIN=J1-39
NET=NetJ1_38|PINS=1
PIN=J1-38
NET=NetJ1_37|PINS=1
PIN=J1-37
NET=NetJ1_36|PINS=1
PIN=J1-36
NET=NetJ1_35|PINS=1
PIN=J1-35
NET=NetJ1_34|PINS=1
PIN=J1-34
NET=NetJ1_33|PINS=1
PIN=J1-33
NET=NetJ1_32|PINS=1
PIN=J1-32
NET=NetJ1_31|PINS=1
PIN=J1-31
NET=NetJ1_30|PINS=1
PIN=J1-30
NET=NetJ1_29|PINS=1
PIN=J1-29
NET=NetJ1_28|PINS=1
PIN=J1-28
NET=NetJ1_27|PINS=1
PIN=J1-27
NET=NetJ1_14|PINS=1
PIN=J1-14
NET=NetJ1_13|PINS=1
PIN=J1-13
NET=MW6|PINS=3
PIN=C6-2
PIN=Q1-18
PIN=R6-1
NET=MW5|PINS=3
PIN=C5-2
PIN=Q1-12
PIN=R5-1
NET=MW4|PINS=3
PIN=C4-2
PIN=Q1-24
PIN=R4-1
NET=MW3|PINS=3
PIN=C3-2
PIN=Q1-1
PIN=R3-1
NET=MW2|PINS=3
PIN=C2-2
PIN=Q1-6
PIN=R2-1
NET=MW1|PINS=3
PIN=C1-2
PIN=Q1-9
PIN=R1-1
NET=GND|PINS=32
PIN=SMP1-2
PIN=SMP1-3
PIN=SMP1-4
PIN=SMP1-5
PIN=SMP2-2
PIN=SMP2-3
PIN=SMP2-4
PIN=SMP2-5
PIN=SMP3-2
PIN=SMP3-3
PIN=SMP3-4
PIN=SMP3-5
PIN=SMP4-2
PIN=SMP4-3
PIN=SMP4-4
PIN=SMP4-5
PIN=SMP5-2
PIN=SMP5-3
PIN=SMP5-4
PIN=SMP5-5
PIN=SMP6-2
PIN=SMP6-3
PIN=SMP6-4
PIN=SMP6-5
PIN=SMP7-2
PIN=SMP7-3
PIN=SMP7-4
PIN=SMP7-5
PIN=SMP8-2
PIN=SMP8-3
PIN=SMP8-4
PIN=SMP8-5
COMPLETE

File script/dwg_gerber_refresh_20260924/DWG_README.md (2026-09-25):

# Split mounting plate drawings - Rev E

Regenerated from the current saved native CAD on 2026-09-24.

## Drawing package

- CP01: central plate, integral boss, mounting pattern and relief grooves.
- CP02: central plate sections, opposed M3 threads, countersinks and groove dimensions.
- LS01 and RS01: separate left and right supports, 1.60 mm outer flanges, C1.6 x 45-degree outer bevels and four plain diameter 3.40 mm rod holes per support.
- AS01: native exploded presentation, fastening axes, assembled view and joint section.

The five sheets are supplied as five single-sheet native Inventor DWGs, a combined five-sheet master DWG and a companion PDF. Each uses ISO A3 landscape paper. All 46 dimensions remain model-associated with no numeric overrides. Keep the included IPT/IAM/IPN files in the supplied directory structure. Part STEP files are included.

Material for all three fabricated parts is oxygen-free copper; surface treatment is NONE. The central deck remains 4 mm thick. Device relief grooves are 3.3398406169 mm wide and 0.5 mm deep. Internal threads are M3x0.5-6H. The eight plate-joining screws are unmodified Autodesk Content Center DIN 7991 M3x10, with 6.6 mm x 90-degree deck countersinks.
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

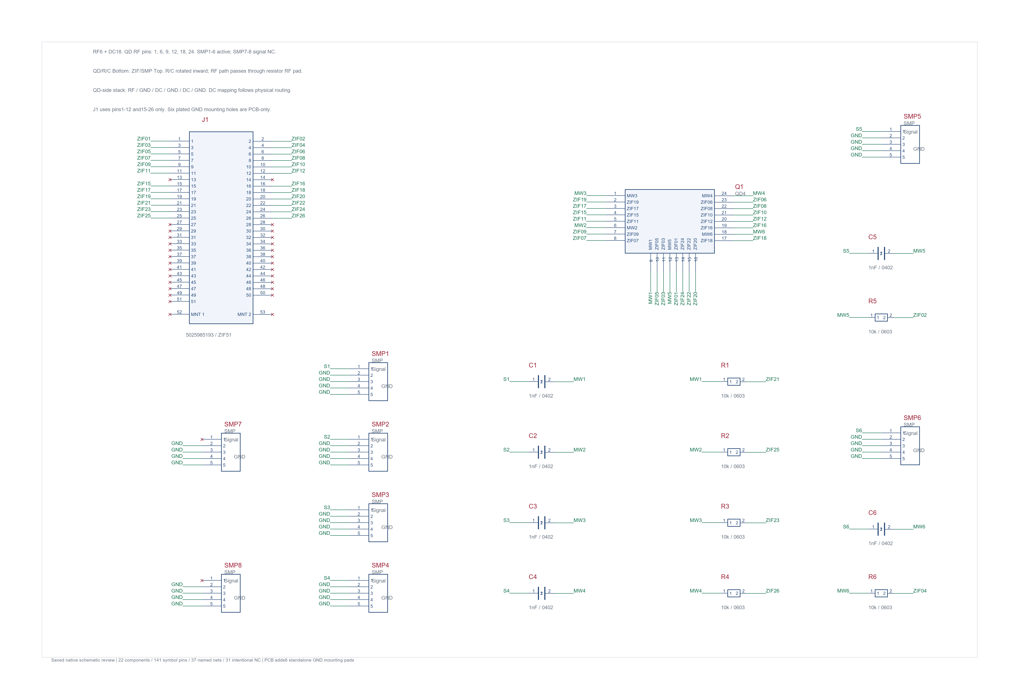
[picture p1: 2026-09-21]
QSTL_24DC_4MW_PCB/docs/schematic.png

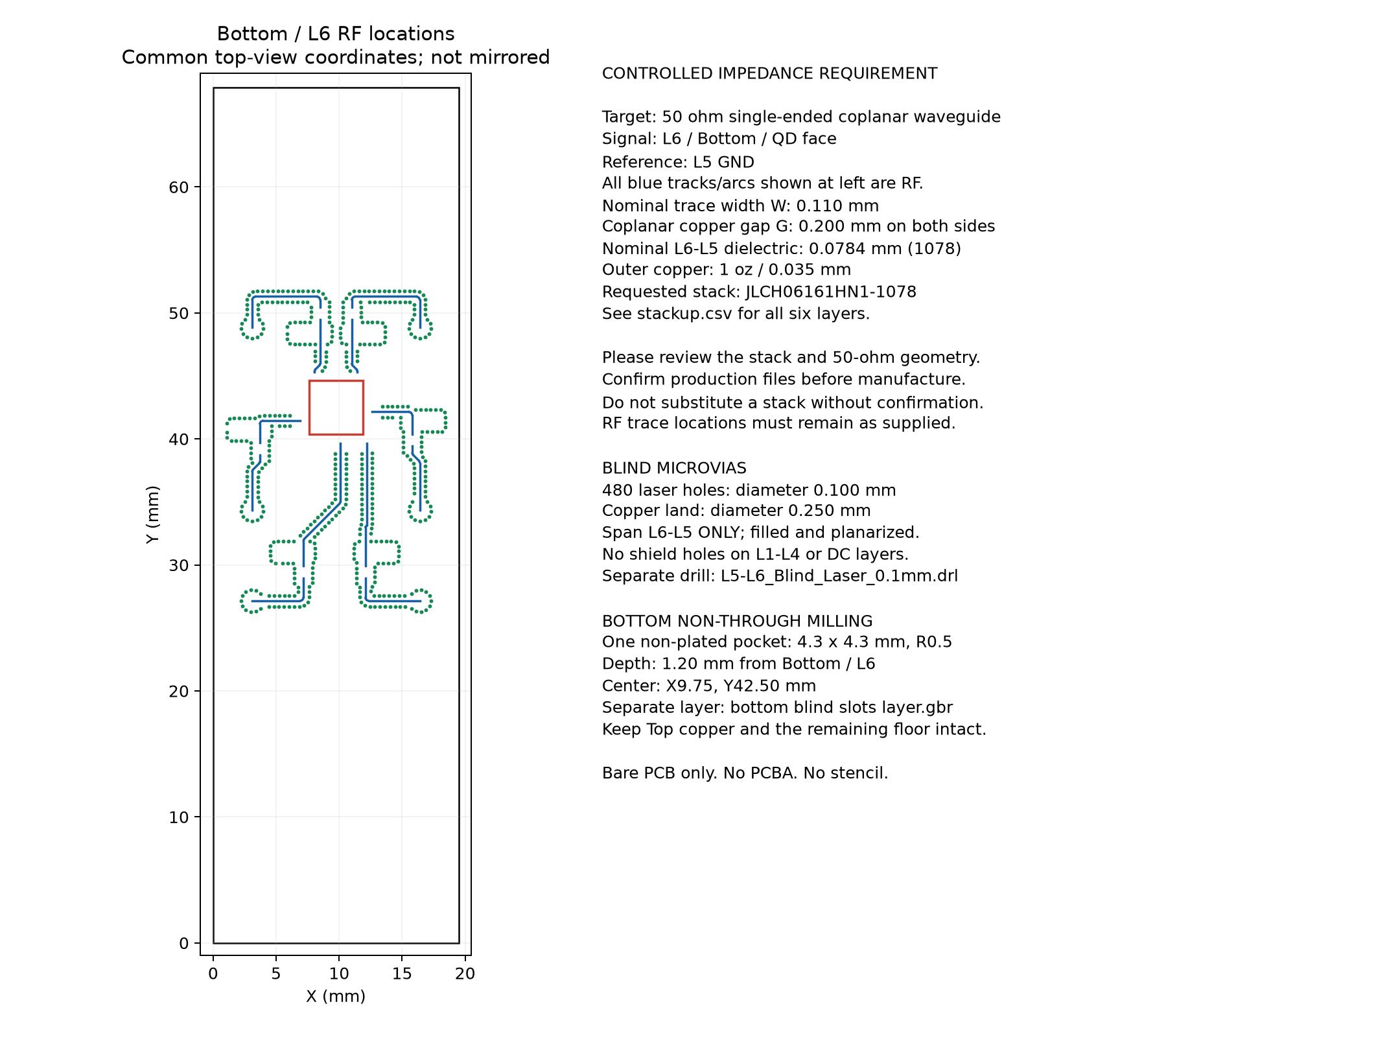
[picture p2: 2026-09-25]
QSTL_24DC_4MW_PCB/fabrication/JLCPCB_HDI_20260922/Gerber/Impedance_50ohm_and_HDI_requirements.jpg

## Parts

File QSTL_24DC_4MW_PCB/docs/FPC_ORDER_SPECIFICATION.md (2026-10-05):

# FPC order specification

Updated: 2026-10-05. Units: mm unless stated otherwise.

**Status: draft ordering specification; unresolved items prevent fabrication release.** This is the order worksheet for the three flex designs. It records saved values separately from proposed supplier options. No order or quote has been submitted for these designs in this documentation task. See [FPC_DRC_AND_MANUFACTURABILITY.md](FPC_DRC_AND_MANUFACTURABILITY.md) for limits, findings and verification requirements.

## Document and decision ownership

- User requirements are maintained in [DESIGN_REQUIREMENTS.md](DESIGN_REQUIREMENTS.md).
- **Current baseline: 18 um copper.** A 12 um alternative is under consideration only; it has not been applied or approved as the selected order stack.
- The 70 mm dimension is the branch's A-to-B output-tip separation. It is not the overall cable length and did not shorten the original 101.6 mm straight cable.
- Use separate manufacturing packages and order line items for each design. Quantity, delivery address, shipping method, price and lead time remain unspecified.

## Board-specific order worksheet

| Setting | Straight cable | Branched cable | Micro-D adapter |
| --- | --- | --- | --- |
| Project | [FPC_15015_0451](../FPC_15015_0451/FPC_15015_0451.PrjPcb) | [ZIF_to_2xZIF](../FPC_Adapters_20261002/ZIF_to_2xZIF/ZIF_to_2xZIF.PrjPcb) | [ZIF_to_DSUB25](../FPC_Adapters_20261002/ZIF_to_DSUB25/ZIF_to_DSUB25.PrjPcb) |
| Fabrication category | Flexible PCB | Flexible PCB | Flexible PCB with bonded connector backing |
| Copper layers | 1 | 2 | 2 |
| Saved copper per layer | 18 um / 0.5 oz | 18 um / 0.5 oz | 18 um / 0.5 oz |
| Finished outline envelope | 101.60 x 15.60 | 420.00 x 41.20 | 40.00 x 31.00 |
| Mechanical status | Molex nominal reconstruction | 420 overall and 10 clear strip gap remain provisional; 70 tip separation confirmed | 40 length and 31 base are provisional |
| Contact ends | A/B on Top | A/B on Top; C on Bottom | A on Top |
| Contacts at each end | 51; 0.30 pitch; 15.60 mating width | Same | Same |
| Contact exposure / backing length | 3.00 / 4.00 | 3.00 / 4.00 | 3.00 / 4.00 |
| Finished mating thickness target | 0.20 +/- 0.03 | 0.20 +/- 0.03 | 0.20 +/- 0.03 |
| Drilling in current artwork | None | 51 plated through vias, 0.10 drill / 0.30 land | 12 plated through vias, 0.20 / 0.40; 25 signal PTHs, 0.7112 / 0.9652; two boardlocks, 2.69 drill |
| Special processing | Contact-gap issue unresolved | Extreme fine drilling plus contact-gap issue | Contact gap and PTH annulus unresolved; via-process confirmation |
| Electrical topology | A.n = B.n, all 51 | C.n = A.n = B.n, all 51 | Anton Micro-D map; odd contacts NC |

The Micro-D connector is NorComp 381-025-112L565, not a full-size DB25. DSUB pins 1..13 map to ZIF 2,6,...50; pins 14..25 map to 4,8,...48. Preserve [contact_mapping.csv](../FPC_Adapters_20261002/ZIF_to_DSUB25/contact_mapping.csv). The adapter uses contact 50; the carrier's separate unused-pin-50 rule does not apply here.

## Common order fields

| Field | Intended setting / status |
| --- | --- |
| Supplier | JLCPCB FPC service, subject to the manufacturing findings being resolved |
| Material | Polyimide flex; actual core, adhesive and coverlay construction to be matched to a supplier stack |
| Coverlay color | Yellow proposed for the quote; not yet an approved or selected order option |
| Surface finish | ENIG 2 microinch proposed for supplier review; see the source-cable finish difference below |
| Impedance option | No controlled-impedance requirement specified for these flex interconnects; do not import the carrier's 50-ohm HDI settings |
| Blind/buried vias | None; the adapter vias are through vias connecting the two flex copper layers |
| Milling / cavity | No QD blind pocket, Z-milling or carrier mechanical fabrication layer belongs in these packages |
| Via coverlay | Covered on both faces; verify exported apertures, not only cached pad flags |
| Paste / stencil | No paste artwork or stencil required for this cable fabrication package |
| PCBA | Bare-board fabrication worksheet; assembly service not included in the proposed scope |
| Silkscreen | None proposed; keep engineering annotations on fabrication documentation layers |
| Electrical test | Request continuity/isolation against the released netlist, including the three-end branch map and intended Micro-D NC contacts |
| Edge finish | Laser outline; no V-score instruction |
| Quantity / price / lead time | TBD; no verified quote exists |

JLCPCB lists ENIG in 1 or 2 microinch and lists 12 um copper for two-/four-layer flex; its single-layer list contains 18 and 35 um. [FPC capability source, checked 2026-10-05](https://jlcpcb.com/capabilities/flex-pcb-capabilities)

The straight cable reconstruction's source calls for hard gold. ENIG is a proposed process substitution, not proof of equivalent contact wear or mating-cycle life. Confirm acceptability before release, particularly if repeated insertion is expected. This issue is independent of copper thickness.

## Stack and stiffener specification

| Region | Saved nominal construction | Ordering disposition |
| --- | --- | --- |
| Straight body | 18 um copper + 45 um PI/adhesive + 50 um coverlay/adhesive = 0.113 | Reconstruction stack; do not enter 0.113 as if it were an available catalog option |
| Straight exposed contact | 45 + 18 + 150 um backing/adhesive = 0.213 before plating | Nominal arithmetic only; verify finished thickness and tolerance with the fabricator |
| Adapter body | 18 + 45 + 18 + 25 + 25 um = 0.131 | Draft two-layer construction; replace with an agreed supplier stack before export |
| ZIF contact backing | 4 mm long, on the face opposite each exposed contact array | Select PI backing and adhesive using the actual local copper/coverlay stack to meet 0.20 +/- 0.03 |
| Micro-D connector base | Bonded backing; provisional finished mounting thickness 1.60 | Backing material, adhesive, hole alignment and thickness still need definition; 1.60 is not an instruction to add a 1.60-thick stiffener |

Use the [JLCPCB PI thickness calculator](https://jlcpcb.com/gold-fingers-pi-thickness-calculator) with the selected supplier stack. Record its inputs, proposed backing and supplier-confirmed finished thickness. Account for the absent coverlay over exposed contacts and for the opposite face's actual local construction; do not use the body thickness indiscriminately. No calculator result is recorded yet.

Mechanical 2 currently describes backing boundaries rather than native stiffener solids. Create a fabrication layer map with separate Top-side and Bottom-side backing files and explicit material/thickness notes. On the branch, A/B require Bottom backing and C requires Top backing. On the straight cable and Micro-D mating tail, backing is on Bottom. The connector-base backing must be distinguished from the thin mating-tail backing.

## Copper selection paths

| Path | Required work before ordering |
| --- | --- |
| Retain 18 um baseline | Revise the contact transitions to satisfy the applicable regular limits while retaining mating dimensions, or obtain specific process acceptance. A zero stored-rule DRC is insufficient. |
| Change two-layer adapters to 12 um | First select this design change; update native stack, fabrication notes, rules and reports. Current 0.0707105 contact gaps fit the published 2/2 mil absolute capability, but are below the regular 3/3 mil spacing. Confirm the actual artwork's acceptance. Resolve the Micro-D annulus independently. |
| Change straight single-layer cable to 12 um | Not a listed single-layer option. Obtain an explicit supplier offer or revise the construction; do not silently order two layers or add copper. |

For the 12 um option, record allowable current and voltage drop before acceptance. With unchanged length/width/material, copper resistance rises by 50%; finished connector thickness must be recalculated. The current 18 um files must not be sent with an unrecorded 12 um order selection.

Do not describe 2/2 mil as a verified separate order option or assume a surcharge for it. Line/space pricing remains unconfirmed; the fine-via extra cost is a separate published condition.

## Panel and fabrication package

Proposed delivery is individual finished circuits with manufacturer panelization reviewed before production. Do not assume the supplier will add handling features without confirming the panel drawing. The branch envelope plus 5 mm handling edges is 51.2 x 430 mm; this is only a size estimate, not a complete panel design.

For panel preparation, use 5 mm handling edges, 2 mm circuit spacing (3 mm for metal stiffeners), and laser tabs rather than V-cuts or mouse bites. Coordinate tooling/fiducials and the long branch's support with the fabricator. [JLCPCB flex panel guide](https://jlcpcb.com/blog/design-guidelines-flex-pcb-panels)

The future release archive for each board must include:

| Output | Content and verification |
| --- | --- |
| Copper Gerbers | Top; Bottom only for the two-layer designs. Inspect actual widths, spacing and contact transitions. |
| Coverlay Gerbers | Explicit Top/Bottom mapping; correct exposed contact face, grouped Micro-D row openings and covered vias. |
| Outline Gerber | One unambiguous finished laser outline; no duplicated backing boundary treated as a cutout. |
| Drill files and map | Exact plated/non-plated classification from the accepted source and connector requirements; separate tooling from product holes. Straight cable has no drills. |
| Backing fabrication layers | Filled Top/Bottom backing outlines, material, thickness, adhesive and finished regional thickness targets. |
| Fabrication drawing | Overall/contact dimensions, contact faces, stack, finish, backing and static no-bend junction area. |
| Electrical data | IPC-D-356 or agreed equivalent test netlist plus contact mapping and intentional NC list. |
| Release manifest | Native source and CAM hashes, revision, export date, DRC/copper checks and the exact quote/order settings. |

Do not include the carrier's HDI drill pairs, QD milling layer, obsolete drafts, history files or an unlabeled collection of engineering mechanical layers. Gerbers cannot by themselves communicate the selected copper weight, finished stack and backing requirements.

## Open decisions and final checks

| Item | Current status |
| --- | --- |
| 18 versus 12 um | 18 saved; 12 considered, not selected |
| Minimum contact gap / exposed-contact acceptance | Unresolved; applies to all three designs |
| Branch and Micro-D via process | Supplier-specific confirmation needed |
| Micro-D signal annulus | Below published absolute limit; redesign or accepted exception required |
| Edge/slot, coverlay and pad-to-trace checks | Full supplier-profile/CAM review outstanding |
| Supplier stack and contact backing | Not selected; finished mating target remains binding |
| Contact finish | ENIG proposed; source hard-gold equivalence not established |
| Branch and Micro-D provisional dimensions | Mechanical confirmation outstanding |
| Native library reload / schematic compilation | Final adapter recompile outstanding |
| DRC and independent checks after any revision | Must be regenerated; archived zero reports are not supplier approval |
| Gerbers, panel, quote and order | Not released by this task; quantity and commercial details TBD |

When these items are resolved, replace proposals with the exact selected options, link the supplier's written exception/process confirmation where applicable, and retain screenshots of the final quote settings with the release manifest. Update this document whenever geometry, copper, backing or supplier options change.

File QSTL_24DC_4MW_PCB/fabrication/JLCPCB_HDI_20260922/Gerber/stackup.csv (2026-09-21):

layer | function | copper_mm | dielectric_below_mm | dielectric_material
L1 | GND | 0.035 | 0.0784 | 1078RC69%
L2 | DC_A | 0.0152 | 0.55 | 0.55 mm core
L3 | GND | 0.0152 | 0.2008 | 7628RC50%
L4 | DC_B | 0.0152 | 0.55 | 0.55 mm core
L5 | GND reference | 0.0152 | 0.0784 | 1078RC69%
L6 | RF/QD/RC | 0.035

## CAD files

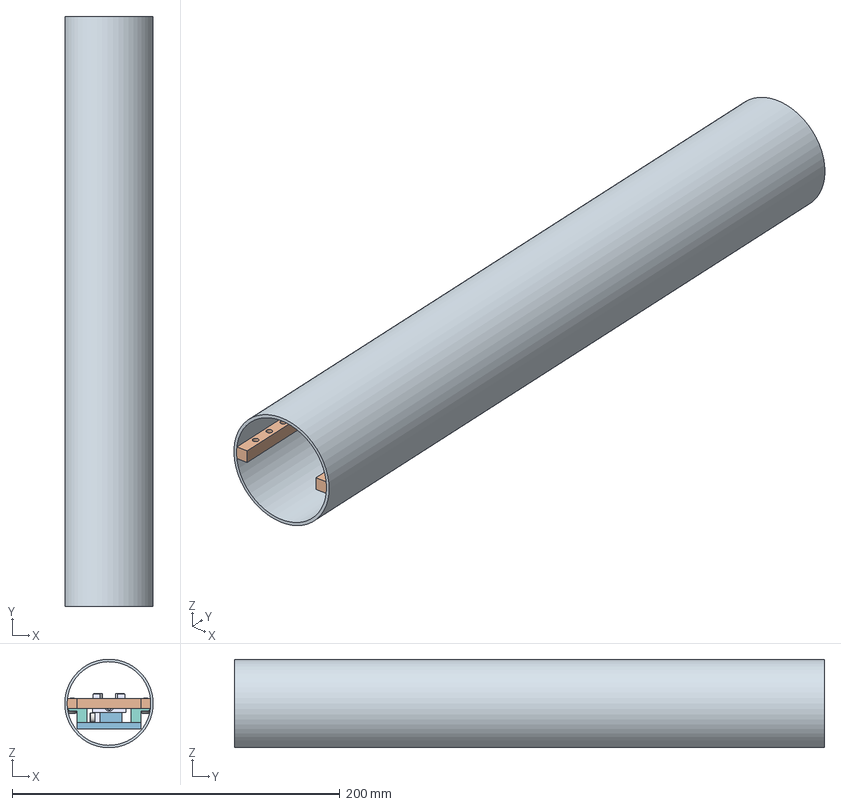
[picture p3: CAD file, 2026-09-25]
QSTL_24DC_4MW_PCB/Mechanical_Assembly/Rod_Holder_Adapter_Drop8p5/Rod_Holder_Assembly_Drop8p5.step
53.9 x 360.0 x 54.0 mm
Probe_H_Frame
Centre_Plate
Bottom
PCB_board
R6
R5
R4
R3
R2
R1
C6
C5
C4
C3
C2
C1
J1
Top_ForFridge
ISO 4762 - M3 x 8 x 2
ISO 7380-1 - M3 x 8 x 8
Probe_Tube
Left_Rod_Support
Right_Rod_Support
DIN 7991 - M3x10 x 8

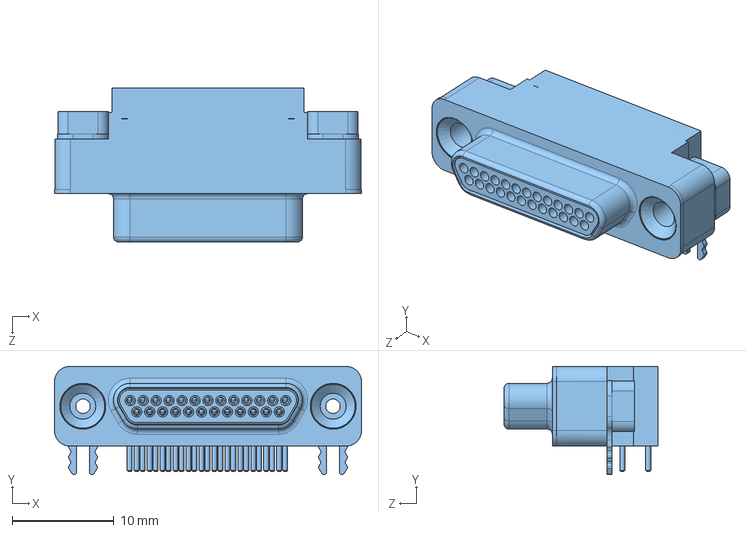
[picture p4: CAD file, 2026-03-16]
QSTL_24DC_4MW_PCB/581-M25-113L461.STEP
30.1 x 10.6 x 15.1 mm

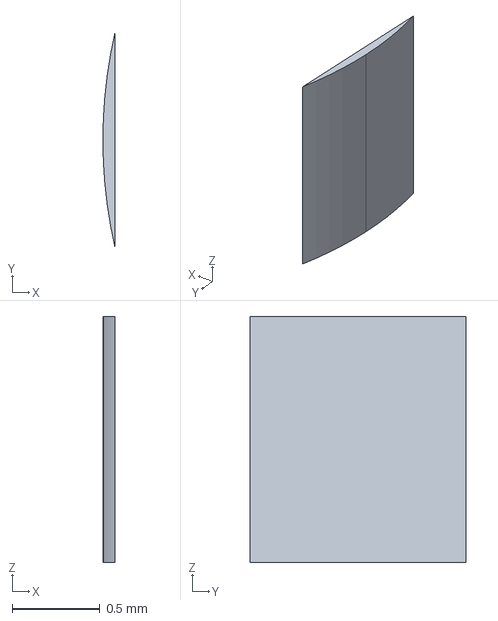
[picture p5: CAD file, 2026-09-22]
QSTL_24DC_4MW_PCB/Mechanical_Assembly/Interference_Bottom_SMP1.step
0.0698 x 1.23 x 1.40 mm

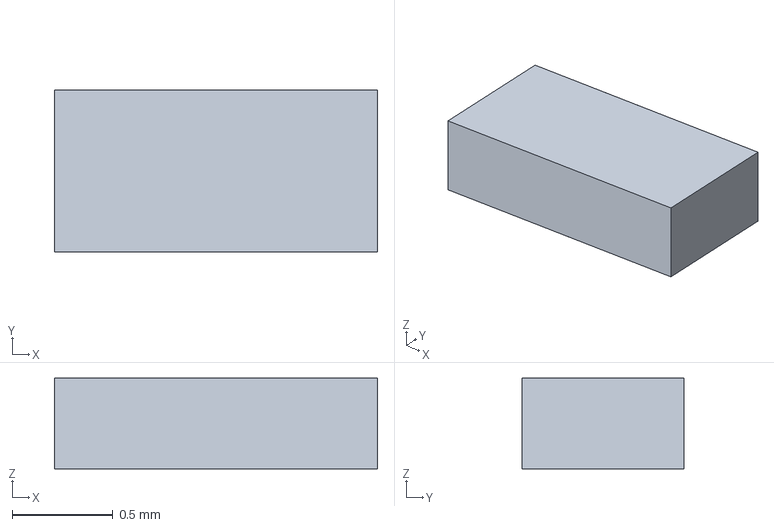
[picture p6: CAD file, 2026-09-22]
QSTL_24DC_4MW_PCB/Mechanical_Assembly/PCB_parts/R3.step
1.60 x 0.8 x 0.45 mm

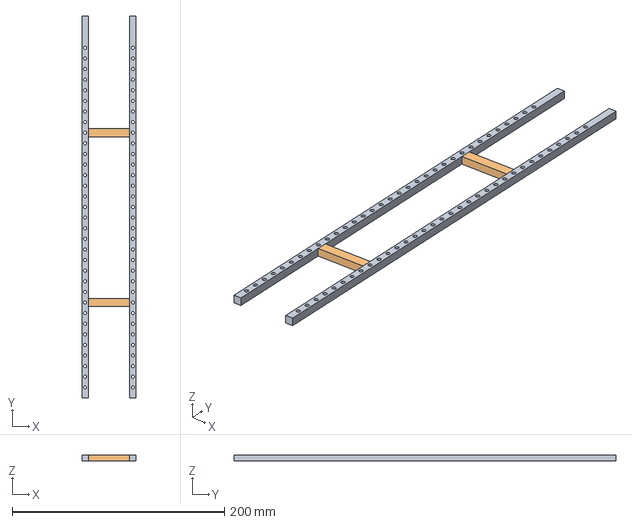
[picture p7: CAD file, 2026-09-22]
QSTL_24DC_4MW_PCB/Mechanical_Assembly/Probe_H_Frame/Probe_H_Frame.step
51.0 x 360.0 x 6.00 mm

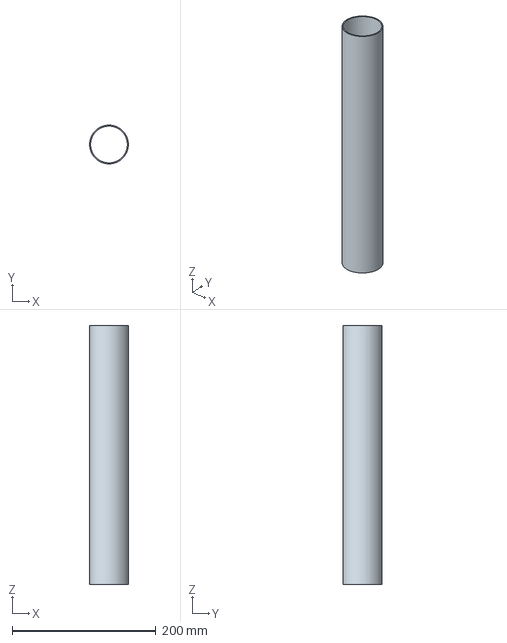
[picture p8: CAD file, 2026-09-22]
QSTL_24DC_4MW_PCB/Mechanical_Assembly/Probe_Tube/Probe_Tube.step
53.9 x 54.0 x 360.0 mm

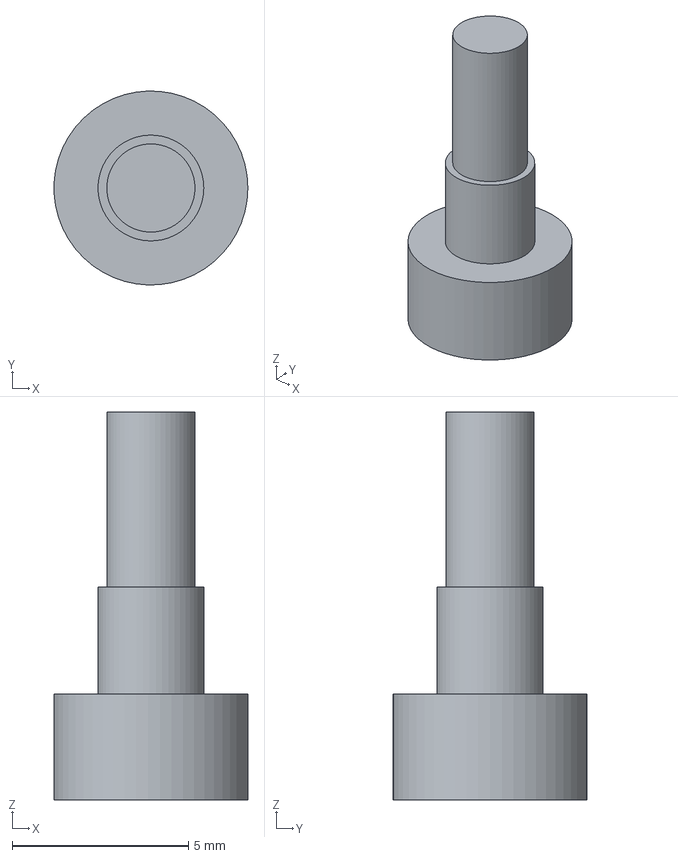
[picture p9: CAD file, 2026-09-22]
QSTL_24DC_4MW_PCB/Mechanical_Assembly/Rod_Holder_Adapter/Device_M3x8_Simplified.step
5.49 x 5.50 x 11.0 mm

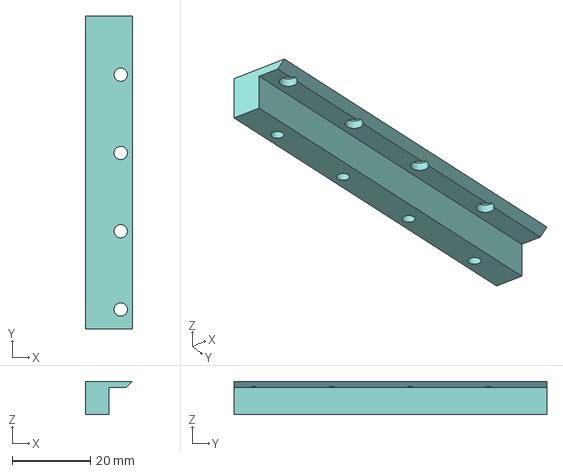
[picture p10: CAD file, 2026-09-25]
QSTL_24DC_4MW_PCB/Mechanical_Assembly/Rod_Holder_Adapter_Drop8p5/STEP_Parts_20260929/RS-01_Right_Rod_Support.step
12.0 x 80.0 x 8.50 mm

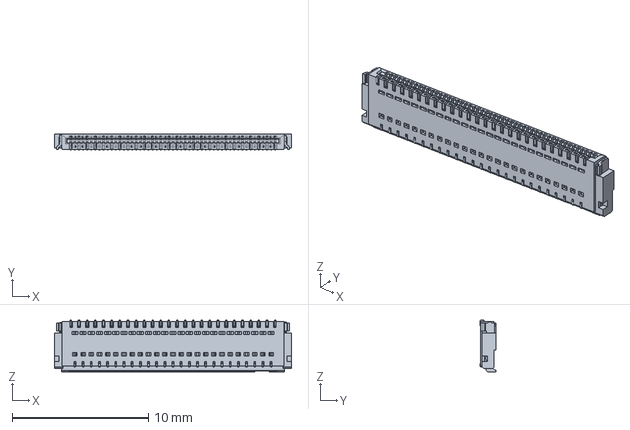
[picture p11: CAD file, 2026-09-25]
QSTL_24DC_4MW_PCB/Mechanical_Assembly/ZIF_M1_Review/J1_embedded.step
17.4 x 1.15 x 3.80 mm

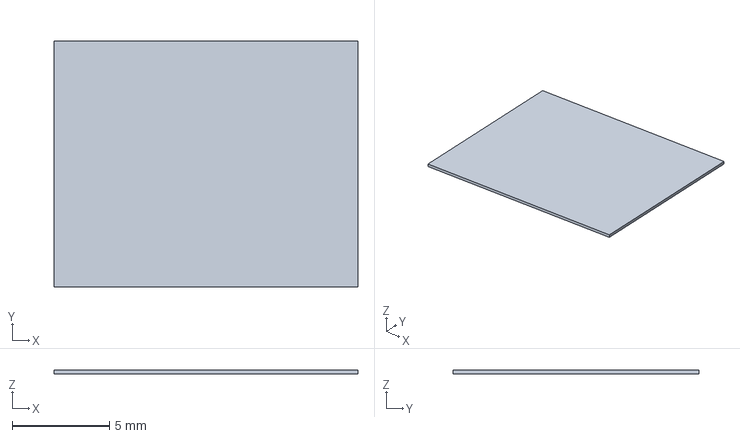
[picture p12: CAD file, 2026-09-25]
QSTL_24DC_4MW_PCB/Mechanical_Assembly/ZIF_M1p6_Review/FPC_51_0p3_Envelope.step
15.6 x 12.6 x 0.2 mm

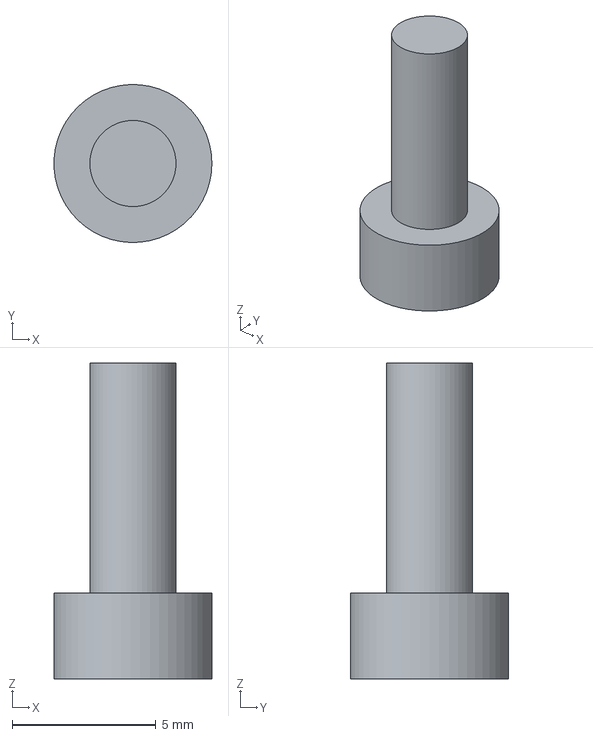
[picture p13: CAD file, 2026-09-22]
QSTL_24DC_4MW_PCB/Mechanical_Assembly/Rod_Holder_Adapter/Rod_M3x8_Simplified.step
5.49 x 5.50 x 11.0 mm

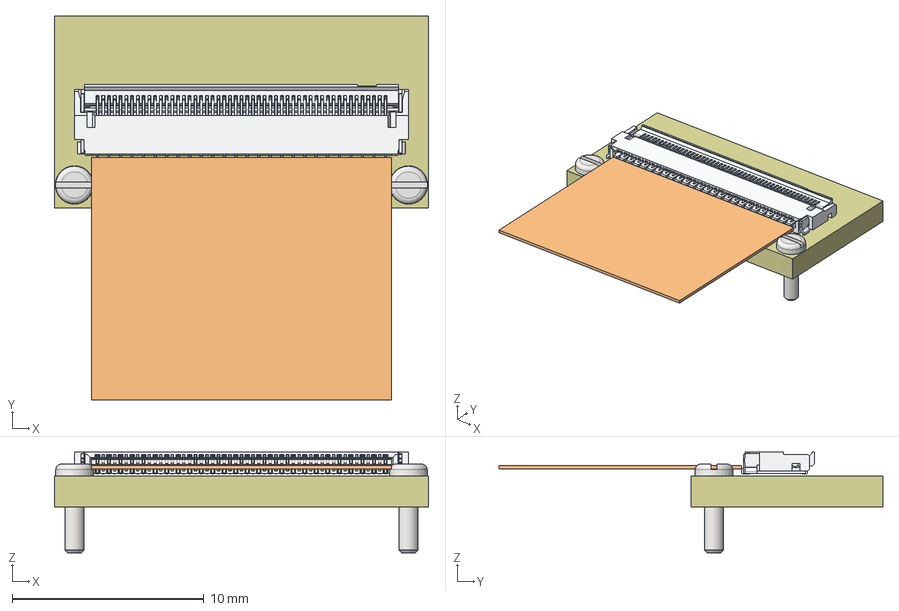
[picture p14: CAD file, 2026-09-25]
QSTL_24DC_4MW_PCB/Mechanical_Assembly/ZIF_M1_Review/ZIF_M1_Fit.step
19.5 x 20.0 x 5.26 mm
PCB_End
J1_Current
FPC_51_0p3_Envelope
KS B 1021 - M 1 x 4 x 2

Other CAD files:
QSTL_24DC_4MW_PCB/Mechanical_Assembly/Rod_Holder_Adapter/Rod_Holder_Assembly.step
QSTL_24DC_4MW_PCB/Mechanical_Assembly/Rod_Holder_Adapter_Drop8p5/Manufacturing_DWG/QSTL_Split_Mount_RevE_QSTL-CP02.dwg
script/mechanical_assembly_20260921/embedded_models/model_2.step
QSTL_24DC_4MW_PCB/Mechanical_Assembly/Interference_Bottom_SMP3.step
QSTL_24DC_4MW_PCB/Mechanical_Assembly/PCB_parts/R1.step
QSTL_24DC_4MW_PCB/Mechanical_Assembly/Rod_Holder_Adapter_Drop8p5/STEP_Parts_20260929/LS-01_Left_Rod_Support.step
QSTL_24DC_4MW_PCB/Mechanical_Assembly/Bottom.ipt
QSTL_24DC_4MW_PCB/Mechanical_Assembly/Bottom_reference.step
QSTL_24DC_4MW_PCB/Mechanical_Assembly/Carrier_exploded.iam
QSTL_24DC_4MW_PCB/Mechanical_Assembly/Carrier_with_PCB.iam
QSTL_24DC_4MW_PCB/Mechanical_Assembly/Carrier_with_PCB.step
QSTL_24DC_4MW_PCB/Mechanical_Assembly/Carrier_with_PCB_geometry.step
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

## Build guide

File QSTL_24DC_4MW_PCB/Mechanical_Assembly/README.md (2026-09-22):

# Current PCB carrier assembly

Prepared 2026-09-21 using the current saved PCB and the read-only `Bottom.SLDPRT` and **`Top_ForFridge.SLDPRT`** from `Carrier_8MW_24DC/Mechanical/Narrow_V3_24DC_8MW`. The upper part in the delivered assemblies is derived from `Top_ForFridge`, superseding the initial `Top` import.

## Open the model

- `Carrier_with_PCB.iam`: assembled Inventor model.
- `Carrier_with_PCB.step`: portable assembled STEP model.
- `Carrier_exploded.iam`: separated review assembly; Bottom is offset by -20 mm and Top_ForFridge by +30 mm from their assembled positions.
- `PCB_simplified.iam` and `PCB_simplified.step`: simplified PCB alone.
- `Assembly_exploded.png`, `Assembly_closed.png`, `PCB_QD_side.png`, and `PCB_SMP_side.png`: Inventor renders.

Keep the native assemblies with `Bottom.ipt`, `Top_ForFridge.ipt`, and the complete `PCB_parts/` folder. The assembly parts contain imported geometry and do not require the original SolidWorks files. Occurrences are grounded at their calculated placements; they are not a parametric mate-constraint model.

## Geometry retained

The PCB outline is 19.5 x 67.9 mm. Thickness from the saved copper/dielectric stack is 1.58839662 mm. All six mounting holes, forty SMP pin drills, eight SMP positions, the ZIF connector, and all twelve R/C positions are retained. The QD-side pocket is 4.3 x 4.3 mm, 1.2 mm deep, with R0.5 internal corners and approximately 0.3884 mm remaining substrate.

Resistors use 1.6 x 0.8 x 0.45 mm rectangular envelopes. Capacitors use 1.0 x 0.5 x 0.553 mm rectangular envelopes. These dimensions are taken from the PCB's embedded models. SMP connectors retain their outer barrel, bore and five pins in simplified form. ZIF uses the source model's 17.4 x 3.8 x 1.15 mm closed-actuator envelope. Twenty-four QD bond pads are shown as separate thin visual solids. Copper routing, solder mask, small vias, solder fillets and tiny component details are omitted.

## Orientation and validation

The SMP/Top PCB face faces Bottom; the QD/R/C/Bottom PCB face faces Top_ForFridge. The PCB uses a proper 180-degree rotation about Y. Eight SMP centres and six mounting centres register to the Bottom hole pattern within 0.000001 mm. Bottom's nominal PCB seat is native Z=2 mm. Top_ForFridge's native seating face is Z=-4.6 mm, translated by +8.18839662 mm to meet the opposite PCB face.

No R/C body intersects either mechanical part. The minimum calculated R/C clearance to either part is approximately 1.667 mm. The following existing geometry overlaps remain uncorrected:

- SMP1/2/3/8 intersect Bottom locally. The user explicitly accepted SMP overlap for this assembly pass. The original embedded connector STEP confirms each overlap, approximately 0.0762 mm3.
- The Top_ForFridge left skirt overlaps the PCB edge by approximately 0.0611 mm laterally, total volume 5.6558 mm3.
- Bottom has a local PCB seating overlap reaching approximately 0.0111 mm, total volume 0.2757 mm3.
- Top_ForFridge and Bottom intersect by approximately 3.5992 mm3 at the adopted nominal seats.

These results document the present fit; no PCB outline or source mechanical geometry was changed to remove the overlaps. Detailed results are in `assembly_validation.json`, with interference STEP files for inspection. `inventor_occurrences.json` records the actual native assembly references and placements. `delivery_verification.json` verifies source-file preservation and exported STEP agreement.

The original PCB and SolidWorks reference files remain unchanged. Helper scripts are in repository-root `script/mechanical_assembly_20260921/`.

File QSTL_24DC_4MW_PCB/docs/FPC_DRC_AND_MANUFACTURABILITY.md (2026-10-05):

# FPC DRC and manufacturability

Reviewed: 2026-10-05. Units: mm unless stated otherwise.

**Status: engineering designs; not released for fabrication.** This document covers the straight FPC, ZIF-to-two-ZIF branch and ZIF-to-Micro-D adapter. It does not change the carrier PCB's HDI rules. Order settings are recorded in [FPC_ORDER_SPECIFICATION.md](FPC_ORDER_SPECIFICATION.md).

## Saved design baseline

The three PCB files matched their saved geometry-validation SHA-256 values during the 2026-10-05 read-only audit. Copper thickness and track/via sizes were also read directly from the PCB binaries. Documentation work has not changed those files.

| Property | Straight FPC | ZIF-to-two-ZIF | ZIF-to-Micro-D |
| --- | --- | --- | --- |
| Project | [FPC_15015_0451](../FPC_15015_0451/FPC_15015_0451.PrjPcb) | [ZIF_to_2xZIF](../FPC_Adapters_20261002/ZIF_to_2xZIF/ZIF_to_2xZIF.PrjPcb) | [ZIF_to_DSUB25](../FPC_Adapters_20261002/ZIF_to_DSUB25/ZIF_to_DSUB25.PrjPcb) |
| Copper layers / thickness per layer | 1 / 18 um | 2 / 18 um | 2 / 18 um |
| Routed track widths | 0.20 | 0.10, 0.20 | 0.10, 0.20 |
| Integral contact neck / wide finger | 0.10 / 0.30 | 0.10 / 0.30 | 0.10 / 0.30 |
| Contact pitch / mating width | 0.30 / 15.60 | 0.30 / 15.60 | 0.30 / 15.60 |
| Minimum different-net copper gap | 0.0707105 | 0.0707105 | 0.0707105 |
| Via count; drill / land diameter | None | 51; 0.10 / 0.30 | 12; 0.20 / 0.40 |
| Connector signal PTH drill / land | None | None | 0.7112 / 0.9652 |
| Connector signal radial annulus | N/A | N/A | 0.127 |
| Boardlock drills | None | None | 2 x 2.69 |

The contact necks/fingers include copper regions, so track-width checks alone do not cover their geometry. The narrowest gap is at opposing diagonal contact transitions. It is not the 0.10 mm gap between the straight 0.20 mm conductors on 0.30 mm pitch. Micro-D radial annulus is `(0.9652 - 0.7112) / 2 = 0.127`.

## Supplier limits

The following compact reference is from [JLCPCB Flex PCB Capabilities](https://jlcpcb.com/capabilities/flex-pcb-capabilities), checked 2026-10-05. Width/space values use `1 mil = 0.0254 mm`.

| Copper | Regular width / space | Absolute width / space limit |
| --- | --- | --- |
| 12 um | 0.0762 / 0.0762 | 0.0508 / 0.0508 |
| 18 um | 0.0889 / 0.0889 | Supplier inquiry |
| 35 um | 0.1016 / 0.1016 | Supplier inquiry |

The 12 um entry's 2/2 mil absolute limit describes manufacturing capability; it is not a verified separate orderable process name. Extra charges for this line/space capability have not been confirmed. This is distinct from the fine-via option's explicitly stated extra cost below.

| Feature | Published limit |
| --- | --- |
| Via drill / land, regular | 0.30 / 0.55 |
| Via drill / land, two-layer extreme | 0.10 / 0.30; extra cost |
| PTH radial annulus | 0.25 recommended; 0.18 absolute |
| Via land to trace | >= 0.10 |
| Exposed pad to trace | >= 0.15 |
| NPTH to copper | >= 0.20 |
| Coverlay expansion / opening-to-trace | 0.10 / >= 0.15 |
| Coverlay bridge | >= 0.50 |
| Copper to outline / slot | >= 0.30 |
| Gold finger to outline | >= 0.20 |
| Silkscreen height / stroke / pad gap | >= 1.00 / 0.15 / 0.15 |
| Trace-width tolerance | +/-20% |

The [FPC product page](https://jlcpcb.com/pcb-fabrication/flexible-pcb) lists a different regular via drill/land pair, 0.15/0.35, while the detailed capability table lists 0.30/0.55. Obtain a written process-specific answer before relying on the smaller regular pair. Do not silently choose the more permissive webpage.

## Findings for the current artwork

| ID | Finding | Required disposition |
| --- | --- | --- |
| FPC-01 | All three contact gaps are below the 18 um regular minimum. Track widths alone pass that minimum. | Revise the transitions while preserving mating compatibility, or obtain explicit acceptance of the actual artwork and stack. No accepted exception is recorded. |
| FPC-02 | The branch drill/land pair is at the published two-layer extreme limit. | Obtain the matching drill process and cost; keep the junction out of bending zones. |
| FPC-03 | Micro-D signal annulus is below the absolute PTH limit. | Enlarge/rework pads and adjacent routing, or document supplier acceptance. Reducing copper thickness does not increase annulus. |
| FPC-04 | Micro-D 0.20/0.40 vias are below the detailed page's regular pair, although above its two-layer extreme pair. | Resolve the conflicting regular-via publications in the quote. Do not label these vias unconditionally standard. |
| FPC-05 | Current checks establish copper containment, not the required copper/finger setback everywhere along the outline. | Measure actual edge/slot clearances, including contact tips and outer fingers; revise or obtain accepted contact-specific geometry. |
| FPC-06 | Individual DSUB mask webs were replaced by grouped row openings. Via openings are closed; contact arrays use grouped openings. | Check opening registration, unrelated copper near exposed pads, residual bridges and final CAM apertures against the chosen flex process. |
| FPC-07 | Saved stack and backing are reconstruction/design assumptions. | Agree a manufacturable stack and finished connector thickness before export. |
| FPC-08 | Recovered local libraries have independent geometry checks, but final native schematic recompile is pending. | Load libraries and recompile both adapter schematics; resolve real messages and compare the resulting pin/net mapping. |

FPC-01 is a trace/space comparison, not blanket approval of exposed-contact geometry at 12 um. The exposed-pad-to-trace and coverlay requirements are separate checks. Have the supplier review the staggered contact artwork explicitly.

## Existing Altium rules versus a fabrication check

The archived native reports contain 13 listed checks and zero reported violations. They establish compliance with their stored rules only. Their rendered mil values are rounded; the geometric clearance threshold is approximately 0.0707 mm.

| Check | Existing reported setting | Interpretation / future release check |
| --- | --- | --- |
| Global copper clearance | About 0.0707; all objects | Permits the reconstructed contacts. It does not enforce 18 um JLCPCB spacing. |
| Track width | Min 0.10; max 0.30 | Retain at least 0.10 for this design. Evaluate copper-region necks separately. |
| Preferred track width | Straight 0.20; adapters 0.254 | Routing preference, not actual minimum geometry or a supplier requirement. Saved adapter tracks are 0.10/0.20. |
| Hole diameter | Min 0.0254; max 2.54, or 2.70 for Micro-D | Minimum is too permissive for a fabrication profile. Separate vias from connector PTH/NPTH holes and bind sizes to the selected process. |
| Hole-to-hole gap | 0.254 | Stored design constraint; not a verified JLCPCB flex hole-spacing specification. Confirm process requirement. |
| Solder-mask sliver | 0.254 | Does not enforce the flex coverlay-bridge minimum. Validate grouped coverlay openings in CAM. |
| Silk-to-mask / silk-to-silk | 0.254 / 0.254 | Does not establish character height, stroke width or every exposed-pad clearance. |
| Short circuit / unrouted / antenna | Shorts disallowed; zero violations | Keep enabled, rebuild connectivity and inspect after save/reopen. |
| PTH annulus, outline setback, flex stack and stiffeners | Not listed as checks in the archived report | Check explicitly; a zero report cannot imply these passed. |

For an 18 um regular-process revision, use at least 0.0889 mm width/space; the proposed project design target is 0.10 mm for both, where mating geometry permits. Use separate rules for via-to-trace, exposed-pad-to-trace, holes and outline setbacks. For a future 12 um revision, distinguish the 0.0762 mm regular profile from contact geometry relying on the published absolute capability. Do not globally lower clearance to 0.0508 mm just to make the report pass. These are documentation targets, not applied rule edits.

## Optional 12 um copper change

The saved and active baseline is still 18 um. The user has asked about 12 um but has not instructed a design change. Keep the order profile and PCB stack consistent if that changes.

At equal conductor length, width, material and temperature, `R12/R18 = 18/12 = 1.5`. At fixed current, trace voltage drop and resistive heating also increase by 50%. This ratio is not an ampacity rating. Check actual branch currents, allowable voltage error and thermal conditions; the common branch conductor carries the combined output current. No maximum load or cryogenic electrical/thermal qualification is recorded.

The current finger gap would still be below the 12 um regular limit. Its size is above the published absolute line/space limit, but other geometry and manufacturing checks remain outstanding. Recalculate the finished ZIF mating thickness rather than simply changing the nominal copper dropdown.

## Evidence and release procedure

| Design | Saved geometry evidence | Archived native DRC |
| --- | --- | --- |
| Straight | [190 checks](../FPC_15015_0451/saved_geometry_validation.json) | [Report](../FPC_15015_0451/Native_DRC.html) |
| Branch | [532 checks](../FPC_Adapters_20261002/ZIF_to_2xZIF/geometry_validation.json) | [Report](../FPC_Adapters_20261002/ZIF_to_2xZIF/Native_DRC.html) |
| Micro-D | [87 checks](../FPC_Adapters_20261002/ZIF_to_DSUB25/geometry_validation.json) | [Report](../FPC_Adapters_20261002/ZIF_to_DSUB25/Native_DRC.html) |

1. Resolve FPC-01 through FPC-08 and record the selected copper/process in the order document. Keep accepted supplier exceptions scoped to the relevant feature.
2. Apply the agreed rules to the editable source, preserving contact numbering, connector geometry and schematic correspondence. Do not alter read-only references.
3. Save/reopen, run native DRC and schematic checks, then repeat independent copper, drill, mask/paste and outline measurements. Do not reuse old reports for changed artwork.
4. Inspect exported Gerbers and drill files, including mirrored contact faces and backing layers. Record the release hashes and corresponding reports.

No new native DRC, Gerbers, quote, supplier exception or fabrication release was produced by this documentation update.

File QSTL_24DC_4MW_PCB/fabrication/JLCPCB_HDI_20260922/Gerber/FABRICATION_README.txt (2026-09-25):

QSTL 24DC 6RF - JLCPCB HDI QUOTATION PACKAGE
Exported from the original saved Altium PCB on 2026-09-22.
Bare PCB only, no assembly or stencil.

LAYER MAP (all files use the same origin; no mirror)
GTL: L1 Top GND
G1: L2 DC A
G2: L3 GND
G3: L4 DC B
G4: L5 GND
GBL: L6 Bottom RF / QD
GTS / GBS: Top / Bottom solder mask
GTO / GBO: Top / Bottom silkscreen
GKO: 19.5 x 67.9 mm closed board outline only

L1-L6_PTH.drl: 94 through plated holes (48 x 0.25 mm,
40 x 0.75 mm, 4 x 2.1 mm, 2 x 4.0 mm).
L5-L6_Blind_Laser_0.1mm.drl: 480 x 0.10 mm blind laser holes,
L6 to L5 ONLY, 0.25 mm copper lands. Filled and planarized.
Do NOT interpret these as through holes. No buried holes.
Excellon: metric, 4:4, leading zeros suppressed.

bottom blind slots layer.gbr: NON-PLATED blind pocket from Bottom,
4.3 x 4.3 mm, internal R0.50, depth 1.20 mm, centered X9.75 Y42.50.
Contour centerline defines finished pocket; 0.01 mm drawing stroke
is not a tool diameter. This is NOT a through-board cutout.
Keep Top copper and approximately 0.3884 mm remaining material.
See QD_cavity_drawing.png for machining side/location/depth.

50 ohm coplanar RF on L6 referenced to L5, W=0.110 mm, gap=0.200 mm.
Requested stack JLCH06161HN1-1078: 1 oz outer / 0.5 oz inner,
nominal 1.6 mm board; see stackup.csv and impedance requirement JPG.
The HDI order-page stack/inner-copper options require engineering
review if they differ from this requested dielectric/copper stack.
Confirm final stack, impedance compensation and production files.
Exposed QD pads are used for wire bonding; confirm surface-finish
suitability before production release. Quote interface finish is
a quotation assumption and does not approve bondability.

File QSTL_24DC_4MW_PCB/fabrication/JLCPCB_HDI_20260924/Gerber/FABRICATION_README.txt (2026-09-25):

QSTL 24DC 6RF - JLCPCB HDI FABRICATION PACKAGE
Exported from the original saved Altium PCB on 2026-09-24.
Bare PCB only, no assembly or stencil.

LAYER MAP (all files use the same origin; no mirror)
GTL: L1 Top GND
G1: L2 DC A with GND copper pour
G2: L3 GND
G3: L4 DC B with GND copper pour
G4: L5 GND
GBL: L6 Bottom RF / QD
GTS / GBS: Top / Bottom solder mask
GTO / GBO: Top / Bottom silkscreen
GKO: 19.5 x 67.9 mm closed board outline only

L2/L4 GND-pour clearance to signal copper: nominal 0.20 mm.
DC traces, pin mapping and RF geometry are unchanged.

L1-L6_PTH.drl: 94 through plated holes (48 x 0.25 mm,
40 x 0.75 mm, 4 x 2.1 mm, 2 x 4.0 mm).
L5-L6_Blind_Laser_0.1mm.drl: 480 x 0.10 mm blind laser holes,
L6 to L5 ONLY, 0.25 mm copper lands. Filled and planarized.
Do NOT interpret these as through holes. No buried holes.
Excellon: metric, 4:4, leading zeros suppressed.

bottom blind slots layer.gbr: NON-PLATED blind pocket from Bottom,
4.3 x 4.3 mm, internal R0.50, depth 1.20 mm, centered X9.75 Y42.50.
Contour centerline defines finished pocket; 0.01 mm drawing stroke
is not a tool diameter. This is NOT a through-board cutout.
Keep Top copper and approximately 0.3884 mm remaining material.
See QD_cavity_drawing.png for machining side/location/depth.

50 ohm coplanar RF on L6 referenced to L5, W=0.110 mm, gap=0.200 mm.
Requested stack JLCH06161HN1-1078: 1 oz outer / 0.5 oz inner,
nominal 1.6 mm board; see stackup.csv and impedance requirement JPG.
The HDI order-page stack/inner-copper options require engineering
review if they differ from this requested dielectric/copper stack.
Confirm final stack, impedance compensation and production files.
Exposed QD pads are used for wire bonding; confirm surface-finish
suitability before production release. Quote interface finish is
a quotation assumption and does not approve bondability.

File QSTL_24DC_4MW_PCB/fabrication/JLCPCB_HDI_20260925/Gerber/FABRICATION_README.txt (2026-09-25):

QSTL 24DC 6RF - JLCPCB HDI FABRICATION PACKAGE
Exported from the original saved Altium PCB on 2026-09-25.
Bare PCB only, no assembly or stencil.

LAYER MAP (all files use the same origin; no mirror)
GTL: L1 Top GND
G1: L2 DC A with GND copper pour
G2: L3 GND
G3: L4 DC B with GND copper pour
G4: L5 GND
GBL: L6 Bottom RF / QD
GTS / GBS: Top / Bottom solder mask
GTO / GBO: Top / Bottom silkscreen
GKO: 19.5 x 67.9 mm closed board outline only

L2/L4 GND-pour clearance to signal copper: nominal 0.20 mm.
DC traces, pin mapping and RF geometry are unchanged.
Two M1 mounts: 1.2 mm plated drill, 1.6 mm land, solid GND.
Centers X1.05 / X18.45, Y1.20 mm; 17.40 mm pitch.
No mounting-hole thermal relief or solder paste.

L1-L6_PTH.drl: 96 through plated holes (48 x 0.25 mm,
40 x 0.75 mm, 2 x 1.2 mm, 4 x 2.1 mm, 2 x 4.0 mm).
L5-L6_Blind_Laser_0.1mm.drl: 480 x 0.10 mm blind laser holes,
L6 to L5 ONLY, 0.25 mm copper lands. Filled and planarized.
Do NOT interpret these as through holes. No buried holes.
Excellon: metric, 4:4, leading zeros suppressed.

bottom blind slots layer.gbr: NON-PLATED blind pocket from Bottom,
4.3 x 4.3 mm, internal R0.50, depth 1.20 mm, centered X9.75 Y42.50.
Contour centerline defines finished pocket; 0.01 mm drawing stroke
is not a tool diameter. This is NOT a through-board cutout.
Keep Top copper and approximately 0.3884 mm remaining material.
See QD_cavity_drawing.png for machining side/location/depth.

50 ohm coplanar RF on L6 referenced to L5, W=0.110 mm, gap=0.200 mm.
Requested stack JLCH06161HN1-1078: 1 oz outer / 0.5 oz inner,
nominal 1.6 mm board; see stackup.csv and impedance requirement JPG.
The HDI order-page stack/inner-copper options require engineering
review if they differ from this requested dielectric/copper stack.
Confirm final stack, impedance compensation and production files.
Exposed QD pads are used for wire bonding; confirm surface-finish
suitability before production release. Quote interface finish is
a quotation assumption and does not approve bondability.

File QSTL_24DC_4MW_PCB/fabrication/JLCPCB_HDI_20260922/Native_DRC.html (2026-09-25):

Altium

# Design Rule Verification Report

Date: | | 2026-09-22
Time: | | 오전 10:35:30
Elapsed Time: | | 00:00:00
Filename: | | C:\JeonghyunPark\Workspace\QSTL_24DC_4MW_PCB\QSTL_24DC_4MW_PCB\QSTL_24DC_4MW_PCB.PcbDoc

Warnings: | | 0
Rule Violations: | | 0

## Summary

Warnings | Count
Total | 0

Rule Violations | Count
Clearance Constraint (Gap=0.15mm) (Not (InNet('GND') And OnLayer('L6_RF_QD'))),(Not (InNet('GND') And OnLayer('L6_RF_QD'))) | 0
Clearance Constraint (Gap=0.2mm) (InNet('GND') And OnLayer('L6_RF_QD')),(All) | 0
Short-Circuit Constraint (Allowed=No) (All),(All) | 0
Un-Routed Net Constraint ( (All) ) | 0
Modified Polygon (Allow modified: No), (Allow shelved: No) | 0
Width Constraint (Min=0.125mm) (Max=0.254mm) (Preferred=0.15mm) (Not OnLayer('L6_RF_QD')) | 0
Width Constraint (Min=0.11mm) (Max=0.11mm) (Preferred=0.11mm) (OnLayer('L6_RF_QD')) | 0
Routing Topology Rule(Topology=Shortest) (All) | 0
Hole Size Constraint (Min=0.025mm) (Max=4.1mm) (All) | 0
Hole To Hole Clearance (Gap=0.254mm) (All),(All) | 0
Minimum Solder Mask Sliver (Gap=0.1mm) (All),(All) | 0
Silk To Solder Mask (Clearance=0.15mm) (IsPad),(All) | 0
Silk to Silk (Clearance=0.254mm) (All),(All) | 0
Net Antennae (Tolerance=0mm) (All) | 0
Height Constraint (Min=0mm) (Max=25.4mm) (Prefered=12.7mm) (All) | 0
Total | 0

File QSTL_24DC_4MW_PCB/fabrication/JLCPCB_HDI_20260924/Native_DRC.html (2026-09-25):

Altium

# Design Rule Verification Report

Date: | | 2026-09-24
Time: | | 오후 11:46:14
Elapsed Time: | | 00:00:00
Filename: | | C:\JeonghyunPark\Workspace\QSTL_24DC_4MW_PCB\QSTL_24DC_4MW_PCB\QSTL_24DC_4MW_PCB.PcbDoc

Warnings: | | 0
Rule Violations: | | 0

## Summary

Warnings | Count
Total | 0

Rule Violations | Count
Clearance Constraint (Gap=0.2mm) (InNet('GND') And OnLayer('L6_RF_QD')),(All) | 0
Clearance Constraint (Gap=0.15mm) (Not (InNet('GND') And OnLayer('L6_RF_QD')) And Not (InNet('GND') And (OnLayer('L2_DC_A') Or OnLayer('L4_DC_B')))),(Not (InNet('GND') And OnLayer('L6_RF_QD')) And Not (InNet('GND') And (OnLayer('L2_DC_A') Or OnLayer('L4_DC_B')))) | 0
Clearance Constraint (Gap=0.2mm) (InNet('GND') And (OnLayer('L2_DC_A') Or OnLayer('L4_DC_B'))),(All) | 0
Short-Circuit Constraint (Allowed=No) (All),(All) | 0
Un-Routed Net Constraint ( (All) ) | 0
Modified Polygon (Allow modified: No), (Allow shelved: No) | 0
Width Constraint (Min=0.125mm) (Max=0.254mm) (Preferred=0.15mm) (Not OnLayer('L6_RF_QD')) | 0
Width Constraint (Min=0.11mm) (Max=0.11mm) (Preferred=0.11mm) (OnLayer('L6_RF_QD')) | 0
Routing Topology Rule(Topology=Shortest) (All) | 0
Hole Size Constraint (Min=0.025mm) (Max=4.1mm) (All) | 0
Hole To Hole Clearance (Gap=0.254mm) (All),(All) | 0
Minimum Solder Mask Sliver (Gap=0.1mm) (All),(All) | 0
Silk To Solder Mask (Clearance=0.15mm) (IsPad),(All) | 0
Silk to Silk (Clearance=0.254mm) (All),(All) | 0
Net Antennae (Tolerance=0mm) (All) | 0
Height Constraint (Min=0mm) (Max=25.4mm) (Prefered=12.7mm) (All) | 0
Total | 0

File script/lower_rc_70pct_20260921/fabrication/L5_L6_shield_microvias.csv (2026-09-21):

x_mm | y_mm | start_layer | stop_layer | drill_mm | land_mm | net | type
15.741310 | 26.556452 | L6 | L5 | .100 | .250 | GND | SMP_RING
16.087949 | 26.317184 | L6 | L5 | .100 | .250 | GND | SMP_RING
16.506073 | 26.266414 | L6 | L5 | .100 | .250 | GND | SMP_RING
16.899898 | 26.415774 | L6 | L5 | .100 | .250 | GND | SMP_RING
17.179201 | 26.731041 | L6 | L5 | .100 | .250 | GND | SMP_RING
17.280001 | 27.139999 | L6 | L5 | .100 | .250 | GND | SMP_RING
17.179201 | 27.548957 | L6 | L5 | .100 | .250 | GND | SMP_RING
16.899898 | 27.864224 | L6 | L5 | .100 | .250 | GND | SMP_RING
16.506073 | 28.013584 | L6 | L5 | .100 | .250 | GND | SMP_RING
16.087949 | 27.962814 | L6 | L5 | .100 | .250 | GND | SMP_RING
15.741310 | 27.723546 | L6 | L5 | .100 | .250 | GND | SMP_RING
15.816453 | 34.998690 | L6 | L5 | .100 | .250 | GND | SMP_RING
15.577185 | 34.652052 | L6 | L5 | .100 | .250 | GND | SMP_RING
15.526415 | 34.233927 | L6 | L5 | .100 | .250 | GND | SMP_RING
15.675775 | 33.840103 | L6 | L5 | .100 | .250 | GND | SMP_RING
15.991042 | 33.560799 | L6 | L5 | .100 | .250 | GND | SMP_RING
16.400000 | 33.459999 | L6 | L5 | .100 | .250 | GND | SMP_RING
16.808958 | 33.560799 | L6 | L5 | .100 | .250 | GND | SMP_RING
17.124225 | 33.840103 | L6 | L5 | .100 | .250 | GND | SMP_RING
17.273585 | 34.233927 | L6 | L5 | .100 | .250 | GND | SMP_RING
17.222815 | 34.652052 | L6 | L5 | .100 | .250 | GND | SMP_RING
16.983547 | 34.998690 | L6 | L5 | .100 | .250 | GND | SMP_RING
15.816453 | 49.498689 | L6 | L5 | .100 | .250 | GND | SMP_RING
15.577185 | 49.152051 | L6 | L5 | .100 | .250 | GND | SMP_RING
15.526415 | 48.733926 | L6 | L5 | .100 | .250 | GND | SMP_RING
15.675775 | 48.340101 | L6 | L5 | .100 | .250 | GND | SMP_RING
15.991042 | 48.060798 | L6 | L5 | .100 | .250 | GND | SMP_RING
16.400000 | 47.959998 | L6 | L5 | .100 | .250 | GND | SMP_RING
16.808958 | 48.060798 | L6 | L5 | .100 | .250 | GND | SMP_RING
17.124225 | 48.340101 | L6 | L5 | .100 | .250 | GND | SMP_RING
17.273585 | 48.733926 | L6 | L5 | .100 | .250 | GND | SMP_RING
17.222815 | 49.152051 | L6 | L5 | .100 | .250 | GND | SMP_RING
16.983547 | 49.498689 | L6 | L5 | .100 | .250 | GND | SMP_RING
2.516452 | 49.498689 | L6 | L5 | .100 | .250 | GND | SMP_RING
2.277184 | 49.152051 | L6 | L5 | .100 | .250 | GND | SMP_RING
2.226414 | 48.733926 | L6 | L5 | .100 | .250 | GND | SMP_RING
2.375774 | 48.340101 | L6 | L5 | .100 | .250 | GND | SMP_RING
2.691041 | 48.060798 | L6 | L5 | .100 | .250 | GND | SMP_RING
3.099999 | 47.959998 | L6 | L5 | .100 | .250 | GND | SMP_RING
3.508957 | 48.060798 | L6 | L5 | .100 | .250 | GND | SMP_RING
3.824224 | 48.340101 | L6 | L5 | .100 | .250 | GND | SMP_RING
3.973584 | 48.733926 | L6 | L5 | .100 | .250 | GND | SMP_RING
3.922814 | 49.152051 | L6 | L5 | .100 | .250 | GND | SMP_RING
3.683546 | 49.498689 | L6 | L5 | .100 | .250 | GND | SMP_RING
3.758689 | 27.723546 | L6 | L5 | .100 | .250 | GND | SMP_RING
3.412051 | 27.962814 | L6 | L5 | .100 | .250 | GND | SMP_RING
2.993926 | 28.013584 | L6 | L5 | .100 | .250 | GND | SMP_RING
2.600101 | 27.864224 | L6 | L5 | .100 | .250 | GND | SMP_RING
2.320798 | 27.548957 | L6 | L5 | .100 | .250 | GND | SMP_RING
2.219998 | 27.139999 | L6 | L5 | .100 | .250 | GND | SMP_RING
2.320798 | 26.731041 | L6 | L5 | .100 | .250 | GND | SMP_RING
2.600101 | 26.415774 | L6 | L5 | .100 | .250 | GND | SMP_RING
2.993926 | 26.266414 | L6 | L5 | .100 | .250 | GND | SMP_RING
3.412051 | 26.317184 | L6 | L5 | .100 | .250 | GND | SMP_RING
3.758689 | 26.556452 | L6 | L5 | .100 | .250 | GND | SMP_RING
2.516452 | 34.998690 | L6 | L5 | .100 | .250 | GND | SMP_RING
2.277184 | 34.652052 | L6 | L5 | .100 | .250 | GND | SMP_RING
2.226414 | 34.233927 | L6 | L5 | .100 | .250 | GND | SMP_RING
2.375774 | 33.840103 | L6 | L5 | .100 | .250 | GND | SMP_RING
2.691041 | 33.560799 | L6 | L5 | .100 | .250 | GND | SMP_RING
3.099999 | 33.459999 | L6 | L5 | .100 | .250 | GND | SMP_RING
3.508957 | 33.560799 | L6 | L5 | .100 | .250 | GND | SMP_RING
3.824224 | 33.840103 | L6 | L5 | .100 | .250 | GND | SMP_RING
3.973584 | 34.233927 | L6 | L5 | .100 | .250 | GND | SMP_RING
3.922814 | 34.652052 | L6 | L5 | .100 | .250 | GND | SMP_RING
3.683546 | 34.998690 | L6 | L5 | .100 | .250 | GND | SMP_RING
11.368763 | 30.158324 | L6 | L5 | .100 | .250 | GND | RC_PERIMETER
11.155042 | 30.496441 | L6 | L5 | .100 | .250 | GND | RC_PERIMETER
11.154999 | 30.896441 | L6 | L5 | .100 | .250 | GND | RC_PERIMETER
11.154999 | 31.296440 | L6 | L5 | .100 | .250 | GND | RC_PERIMETER
11.207664 | 31.692957 | L6 | L5 | .100 | .250 | GND | RC_PERIMETER
11.561237 | 31.880002 | L6 | L5 | .100 | .250 | GND | RC_PERIMETER
12.521237 | 31.880002 | L6 | L5 | .100 | .250 | GND | RC_PERIMETER
12.921237 | 31.880002 | L6 | L5 | .100 | .250 | GND | RC_PERIMETER
13.321236 | 31.880000 | L6 | L5 | .100 | .250 | GND | RC_PERIMETER
13.721235 | 31.880000 | L6 | L5 | .100 | .250 | GND | RC_PERIMETER
14.121234 | 31.880000 | L6 | L5 | .100 | .250 | GND | RC_PERIMETER
14.518434 | 31.832761 | L6 | L5 | .100 | .250 | GND | RC_PERIMETER
14.715000 | 31.484390 | L6 | L5 | .100 | .250 | GND | RC_PERIMETER
14.715000 | 31.084390 | L6 | L5 | .100 | .250 | GND | RC_PERIMETER
14.715000 | 30.684391 | L6 | L5 | .100 | .250 | GND | RC_PERIMETER
14.651352 | 30.289487 | L6 | L5 | .100 | .250 | GND | RC_PERIMETER
14.289037 | 30.119998 | L6 | L5 | .100 | .250 | GND | RC_PERIMETER
13.889037 | 30.119998 | L6 | L5 | .100 | .250 | GND | RC_PERIMETER
13.489038 | 30.119998 | L6 | L5 | .100 | .250 | GND | RC_PERIMETER
13.089039 | 30.119998 | L6 | L5 | .100 | .250 | GND | RC_PERIMETER
12.801237 | 29.842203 | L6 | L5 | .100 | .250 | GND | RC_PERIMETER
12.801237 | 29.442204 | L6 | L5 | .100 | .250 | GND | RC_PERIMETER
12.801237 | 29.042205 | L6 | L5 | .100 | .250 | GND | RC_PERIMETER
12.801237 | 28.642206 | L6 | L5 | .100 | .250 | GND | RC_PERIMETER
12.616183 | 28.287586 | L6 | L5 | .100 | .250 | GND | RC_PERIMETER
11.649004 | 28.247109 | L6 | L5 | .100 | .250 | GND | RC_PERIMETER
11.376083 | 28.539537 | L6 | L5 | .100 | .250 | GND | RC_PERIMETER
11.368763 | 28.939470 | L6 | L5 | .100 | .250 | GND | RC_PERIMETER
11.368763 | 29.339469 | L6 | L5 | .100 | .250 | GND | RC_PERIMETER
11.368763 | 29.739468 | L6 | L5 | .100 | .250 | GND | RC_PERIMETER
16.057110 | 42.330002 | L6 | L5 | .100 | .250 | GND | RC_PERIMETER
16.457110 | 42.330002 | L6 | L5 | .100 | .250 | GND | RC_PERIMETER
16.857109 | 42.330002 | L6 | L5 | .100 | .250 | GND | RC_PERIMETER
17.257108 | 42.330002 | L6 | L5 | .100 | .250 | GND | RC_PERIMETER
17.657107 | 42.330002 | L6 | L5 | .100 | .250 | GND | RC_PERIMETER
18.057106 | 42.329913 | L6 | L5 | .100 | .250 | GND | RC_PERIMETER
18.393225 | 42.113063 | L6 | L5 | .100 | .250 | GND | RC_PERIMETER
18.429999 | 41.714758 | L6 | L5 | .100 | .250 | GND | RC_PERIMETER
18.429999 | 41.314759 | L6 | L5 | .100 | .250 | GND | RC_PERIMETER
18.428340 | 40.914762 | L6 | L5 | .100 | .250 | GND | RC_PERIMETER
18.187182 | 40.595634 | L6 | L5 | .100 | .250 | GND | RC_PERIMETER
17.788004 | 40.570000 | L6 | L5 | .100 | .250 | GND | RC_PERIMETER
17.388004 | 40.570000 | L6 | L5 | .100 | .250 | GND | RC_PERIMETER
16.988005 | 40.570000 | L6 | L5 | .100 | .250 | GND | RC_PERIMETER
16.588006 | 40.570000 | L6 | L5 | .100 | .250 | GND | RC_PERIMETER
16.516236 | 40.176491 | L6 | L5 | .100 | .250 | GND | RC_PERIMETER
16.516236 | 39.776491 | L6 | L5 | .100 | .250 | GND | RC_PERIMETER
16.516236 | 39.376492 | L6 | L5 | .100 | .250 | GND | RC_PERIMETER
16.506081 | 38.976620 | L6 | L5 | .100 | .250 | GND | RC_PERIMETER
15.402207 | 38.688810 | L6 | L5 | .100 | .250 | GND | RC_PERIMETER
15.100694 | 38.951659 | L6 | L5 | .100 | .250 | GND | RC_PERIMETER
15.083762 | 39.351301 | L6 | L5 | .100 | .250 | GND | RC_PERIMETER
15.083762 | 39.751300 | L6 | L5 | .100 | .250 | GND | RC_PERIMETER
15.083762 | 40.151299 | L6 | L5 | .100 | .250 | GND | RC_PERIMETER
15.083762 | 40.551298 | L6 | L5 | .100 | .250 | GND | RC_PERIMETER
14.874446 | 40.892161 | L6 | L5 | .100 | .250 | GND | RC_PERIMETER
14.869998 | 41.292137 | L6 | L5 | .100 | .250 | GND | RC_PERIMETER
14.869998 | 41.692137 | L6 | L5 | .100 | .250 | GND | RC_PERIMETER
10.283764 | 49.241680 | L6 | L5 | .100 | .250 | GND | RC_PERIMETER
10.283764 | 49.641679 | L6 | L5 | .100 | .250 | GND | RC_PERIMETER
10.283764 | 50.041678 | L6 | L5 | .100 | .250 | GND | RC_PERIMETER
10.283764 | 50.441677 | L6 | L5 | .100 | .250 | GND | RC_PERIMETER
10.287833 | 50.841656 | L6 | L5 | .100 | .250 | GND | RC_PERIMETER
10.545722 | 51.147424 | L6 | L5 | .100 | .250 | GND | RC_PERIMETER
11.708270 | 50.863541 | L6 | L5 | .100 | .250 | GND | RC_PERIMETER
11.716240 | 50.463620 | L6 | L5 | .100 | .250 | GND | RC_PERIMETER
11.716240 | 50.063621 | L6 | L5 | .100 | .250 | GND | RC_PERIMETER
11.716240 | 49.663622 | L6 | L5 | .100 | .250 | GND | RC_PERIMETER
11.829537 | 49.280003 | L6 | L5 | .100 | .250 | GND | RC_PERIMETER
12.229536 | 49.280000 | L6 | L5 | .100 | .250 | GND | RC_PERIMETER
12.629535 | 49.280000 | L6 | L5 | .100 | .250 | GND | RC_PERIMETER
13.029535 | 49.280000 | L6 | L5 | .100 | .250 | GND | RC_PERIMETER
13.427126 | 49.236173 | L6 | L5 | .100 | .250 | GND | RC_PERIMETER
13.630003 | 48.891439 | L6 | L5 | .100 | .250 | GND | RC_PERIMETER
13.630003 | 48.491440 | L6 | L5 | .100 | .250 | GND | RC_PERIMETER
13.630003 | 48.091441 | L6 | L5 | .100 | .250 | GND | RC_PERIMETER
13.570519 | 47.695889 | L6 | L5 | .100 | .250 | GND | RC_PERIMETER
13.211266 | 47.519999 | L6 | L5 | .100 | .250 | GND | RC_PERIMETER
12.811267 | 47.519999 | L6 | L5 | .100 | .250 | GND | RC_PERIMETER
12.411268 | 47.519999 | L6 | L5 | .100 | .250 | GND | RC_PERIMETER
12.011269 | 47.519999 | L6 | L5 | .100 | .250 | GND | RC_PERIMETER
11.611270 | 47.520001 | L6 | L5 | .100 | .250 | GND | RC_PERIMETER
10.563271 | 47.520001 | L6 | L5 | .100 | .250 | GND | RC_PERIMETER
10.179581 | 47.633062 | L6 | L5 | .100 | .250 | GND | RC_PERIMETER
10.070000 | 48.017760 | L6 | L5 | .100 | .250 | GND | RC_PERIMETER
10.070000 | 48.417759 | L6 | L5 | .100 | .250 | GND | RC_PERIMETER
10.070000 | 48.817759 | L6 | L5 | .100 | .250 | GND | RC_PERIMETER
5.870001 | 48.900004 | L6 | L5 | .100 | .250 | GND | RC_PERIMETER
6.080544 | 49.240110 | L6 | L5 | .100 | .250 | GND | RC_PERIMETER
6.478549 | 49.280003 | L6 | L5 | .100 | .250 | GND | RC_PERIMETER
6.878549 | 49.280003 | L6 | L5 | .100 | .250 | GND | RC_PERIMETER
7.278548 | 49.280003 | L6 | L5 | .100 | .250 | GND | RC_PERIMETER
7.678547 | 49.280003 | L6 | L5 | .100 | .250 | GND | RC_PERIMETER
7.783764 | 49.665918 | L6 | L5 | .100 | .250 | GND | RC_PERIMETER
7.783764 | 50.065917 | L6 | L5 | .100 | .250 | GND | RC_PERIMETER
7.783764 | 50.465916 | L6 | L5 | .100 | .250 | GND | RC_PERIMETER
8.918407 | 51.157233 | L6 | L5 | .100 | .250 | GND | RC_PERIMETER
9.204952 | 50.878141 | L6 | L5 | .100 | .250 | GND | RC_PERIMETER
9.216238 | 50.478299 | L6 | L5 | .100 | .250 | GND | RC_PERIMETER
9.216238 | 50.078300 | L6 | L5 | .100 | .250 | GND | RC_PERIMETER
9.216238 | 49.678300 | L6 | L5 | .100 | .250 | GND | RC_PERIMETER
9.216238 | 49.278301 | L6 | L5 | .100 | .250 | GND | RC_PERIMETER
9.427982 | 48.938945 | L6 | L5 | .100 | .250 | GND | RC_PERIMETER
9.430001 | 48.538950 | L6 | L5 | .100 | .250 | GND | RC_PERIMETER
9.430001 | 48.138951 | L6 | L5 | .100 | .250 | GND | RC_PERIMETER
9.394876 | 47.740496 | L6 | L5 | .100 | .250 | GND | RC_PERIMETER
9.061018 | 47.520179 | L6 | L5 | .100 | .250 | GND | RC_PERIMETER
8.063019 | 47.520001 | L6 | L5 | .100 | .250 | GND | RC_PERIMETER
7.663020 | 47.520001 | L6 | L5 | .100 | .250 | GND | RC_PERIMETER
7.263021 | 47.520001 | L6 | L5 | .100 | .250 | GND | RC_PERIMETER
6.863022 | 47.520001 | L6 | L5 | .100 | .250 | GND | RC_PERIMETER
6.463022 | 47.520001 | L6 | L5 | .100 | .250 | GND | RC_PERIMETER
6.065868 | 47.567626 | L6 | L5 | .100 | .250 | GND | RC_PERIMETER
5.870001 | 47.916391 | L6 | L5 | .100 | .250 | GND | RC_PERIMETER
5.870001 | 48.316391 | L6 | L5 | .100 | .250 | GND | RC_PERIMETER
4.919998 | 30.120003 | L6 | L5 | .100 | .250 | GND | RC_PERIMETER
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

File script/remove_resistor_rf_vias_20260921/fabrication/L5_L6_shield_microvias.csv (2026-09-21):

x_mm | y_mm | start_layer | stop_layer | drill_mm | land_mm | net | type
15.741310 | 26.556452 | L6 | L5 | .100 | .250 | GND | SMP_RING
16.087949 | 26.317184 | L6 | L5 | .100 | .250 | GND | SMP_RING
16.506073 | 26.266414 | L6 | L5 | .100 | .250 | GND | SMP_RING
16.899898 | 26.415774 | L6 | L5 | .100 | .250 | GND | SMP_RING
17.179201 | 26.731041 | L6 | L5 | .100 | .250 | GND | SMP_RING
17.280001 | 27.139999 | L6 | L5 | .100 | .250 | GND | SMP_RING
17.179201 | 27.548957 | L6 | L5 | .100 | .250 | GND | SMP_RING
16.899898 | 27.864224 | L6 | L5 | .100 | .250 | GND | SMP_RING
16.506073 | 28.013584 | L6 | L5 | .100 | .250 | GND | SMP_RING
16.087949 | 27.962814 | L6 | L5 | .100 | .250 | GND | SMP_RING
15.741310 | 27.723546 | L6 | L5 | .100 | .250 | GND | SMP_RING
15.816453 | 34.998690 | L6 | L5 | .100 | .250 | GND | SMP_RING
15.577185 | 34.652052 | L6 | L5 | .100 | .250 | GND | SMP_RING
15.526415 | 34.233927 | L6 | L5 | .100 | .250 | GND | SMP_RING
15.675775 | 33.840103 | L6 | L5 | .100 | .250 | GND | SMP_RING
15.991042 | 33.560799 | L6 | L5 | .100 | .250 | GND | SMP_RING
16.400000 | 33.459999 | L6 | L5 | .100 | .250 | GND | SMP_RING
16.808958 | 33.560799 | L6 | L5 | .100 | .250 | GND | SMP_RING
17.124225 | 33.840103 | L6 | L5 | .100 | .250 | GND | SMP_RING
17.273585 | 34.233927 | L6 | L5 | .100 | .250 | GND | SMP_RING
17.222815 | 34.652052 | L6 | L5 | .100 | .250 | GND | SMP_RING
16.983547 | 34.998690 | L6 | L5 | .100 | .250 | GND | SMP_RING
15.816453 | 49.498689 | L6 | L5 | .100 | .250 | GND | SMP_RING
15.577185 | 49.152051 | L6 | L5 | .100 | .250 | GND | SMP_RING
15.526415 | 48.733926 | L6 | L5 | .100 | .250 | GND | SMP_RING
15.675775 | 48.340101 | L6 | L5 | .100 | .250 | GND | SMP_RING
15.991042 | 48.060798 | L6 | L5 | .100 | .250 | GND | SMP_RING
16.400000 | 47.959998 | L6 | L5 | .100 | .250 | GND | SMP_RING
16.808958 | 48.060798 | L6 | L5 | .100 | .250 | GND | SMP_RING
17.124225 | 48.340101 | L6 | L5 | .100 | .250 | GND | SMP_RING
17.273585 | 48.733926 | L6 | L5 | .100 | .250 | GND | SMP_RING
17.222815 | 49.152051 | L6 | L5 | .100 | .250 | GND | SMP_RING
16.983547 | 49.498689 | L6 | L5 | .100 | .250 | GND | SMP_RING
2.516452 | 49.498689 | L6 | L5 | .100 | .250 | GND | SMP_RING
2.277184 | 49.152051 | L6 | L5 | .100 | .250 | GND | SMP_RING
2.226414 | 48.733926 | L6 | L5 | .100 | .250 | GND | SMP_RING
2.375774 | 48.340101 | L6 | L5 | .100 | .250 | GND | SMP_RING
2.691041 | 48.060798 | L6 | L5 | .100 | .250 | GND | SMP_RING
3.099999 | 47.959998 | L6 | L5 | .100 | .250 | GND | SMP_RING
3.508957 | 48.060798 | L6 | L5 | .100 | .250 | GND | SMP_RING
3.824224 | 48.340101 | L6 | L5 | .100 | .250 | GND | SMP_RING
3.973584 | 48.733926 | L6 | L5 | .100 | .250 | GND | SMP_RING
3.922814 | 49.152051 | L6 | L5 | .100 | .250 | GND | SMP_RING
3.683546 | 49.498689 | L6 | L5 | .100 | .250 | GND | SMP_RING
3.758689 | 27.723546 | L6 | L5 | .100 | .250 | GND | SMP_RING
3.412051 | 27.962814 | L6 | L5 | .100 | .250 | GND | SMP_RING
2.993926 | 28.013584 | L6 | L5 | .100 | .250 | GND | SMP_RING
2.600101 | 27.864224 | L6 | L5 | .100 | .250 | GND | SMP_RING
2.320798 | 27.548957 | L6 | L5 | .100 | .250 | GND | SMP_RING
2.219998 | 27.139999 | L6 | L5 | .100 | .250 | GND | SMP_RING
2.320798 | 26.731041 | L6 | L5 | .100 | .250 | GND | SMP_RING
2.600101 | 26.415774 | L6 | L5 | .100 | .250 | GND | SMP_RING
2.993926 | 26.266414 | L6 | L5 | .100 | .250 | GND | SMP_RING
3.412051 | 26.317184 | L6 | L5 | .100 | .250 | GND | SMP_RING
3.758689 | 26.556452 | L6 | L5 | .100 | .250 | GND | SMP_RING
2.516452 | 34.998690 | L6 | L5 | .100 | .250 | GND | SMP_RING
2.277184 | 34.652052 | L6 | L5 | .100 | .250 | GND | SMP_RING
2.226414 | 34.233927 | L6 | L5 | .100 | .250 | GND | SMP_RING
2.375774 | 33.840103 | L6 | L5 | .100 | .250 | GND | SMP_RING
2.691041 | 33.560799 | L6 | L5 | .100 | .250 | GND | SMP_RING
3.099999 | 33.459999 | L6 | L5 | .100 | .250 | GND | SMP_RING
3.508957 | 33.560799 | L6 | L5 | .100 | .250 | GND | SMP_RING
3.824224 | 33.840103 | L6 | L5 | .100 | .250 | GND | SMP_RING
3.973584 | 34.233927 | L6 | L5 | .100 | .250 | GND | SMP_RING
3.922814 | 34.652052 | L6 | L5 | .100 | .250 | GND | SMP_RING
3.683546 | 34.998690 | L6 | L5 | .100 | .250 | GND | SMP_RING
12.733764 | 30.158324 | L6 | L5 | .100 | .250 | GND | RC_PERIMETER
12.520044 | 30.496441 | L6 | L5 | .100 | .250 | GND | RC_PERIMETER
12.520000 | 30.896441 | L6 | L5 | .100 | .250 | GND | RC_PERIMETER
12.520000 | 31.296440 | L6 | L5 | .100 | .250 | GND | RC_PERIMETER
12.572665 | 31.692957 | L6 | L5 | .100 | .250 | GND | RC_PERIMETER
13.794237 | 31.880002 | L6 | L5 | .100 | .250 | GND | RC_PERIMETER
14.194236 | 31.880002 | L6 | L5 | .100 | .250 | GND | RC_PERIMETER
14.594235 | 31.880000 | L6 | L5 | .100 | .250 | GND | RC_PERIMETER
14.994235 | 31.880000 | L6 | L5 | .100 | .250 | GND | RC_PERIMETER
15.394234 | 31.880000 | L6 | L5 | .100 | .250 | GND | RC_PERIMETER
15.794058 | 31.868156 | L6 | L5 | .100 | .250 | GND | RC_PERIMETER
16.071461 | 31.579977 | L6 | L5 | .100 | .250 | GND | RC_PERIMETER
16.080001 | 31.180070 | L6 | L5 | .100 | .250 | GND | RC_PERIMETER
16.080001 | 30.780071 | L6 | L5 | .100 | .250 | GND | RC_PERIMETER
16.060730 | 30.380536 | L6 | L5 | .100 | .250 | GND | RC_PERIMETER
15.753941 | 30.123864 | L6 | L5 | .100 | .250 | GND | RC_PERIMETER
15.353960 | 30.119998 | L6 | L5 | .100 | .250 | GND | RC_PERIMETER
14.953960 | 30.119998 | L6 | L5 | .100 | .250 | GND | RC_PERIMETER
14.553961 | 30.119998 | L6 | L5 | .100 | .250 | GND | RC_PERIMETER
14.166238 | 30.021657 | L6 | L5 | .100 | .250 | GND | RC_PERIMETER
14.166238 | 29.621658 | L6 | L5 | .100 | .250 | GND | RC_PERIMETER
14.166238 | 29.221659 | L6 | L5 | .100 | .250 | GND | RC_PERIMETER
14.166238 | 28.821659 | L6 | L5 | .100 | .250 | GND | RC_PERIMETER
14.115923 | 28.424835 | L6 | L5 | .100 | .250 | GND | RC_PERIMETER
13.013705 | 28.247190 | L6 | L5 | .100 | .250 | GND | RC_PERIMETER
12.741026 | 28.539844 | L6 | L5 | .100 | .250 | GND | RC_PERIMETER
12.733764 | 28.939777 | L6 | L5 | .100 | .250 | GND | RC_PERIMETER
12.733764 | 29.339776 | L6 | L5 | .100 | .250 | GND | RC_PERIMETER
12.733764 | 29.739775 | L6 | L5 | .100 | .250 | GND | RC_PERIMETER
16.057110 | 42.330002 | L6 | L5 | .100 | .250 | GND | RC_PERIMETER
16.457110 | 42.330002 | L6 | L5 | .100 | .250 | GND | RC_PERIMETER
16.857109 | 42.330002 | L6 | L5 | .100 | .250 | GND | RC_PERIMETER
17.257108 | 42.330002 | L6 | L5 | .100 | .250 | GND | RC_PERIMETER
17.657107 | 42.330002 | L6 | L5 | .100 | .250 | GND | RC_PERIMETER
18.057106 | 42.329913 | L6 | L5 | .100 | .250 | GND | RC_PERIMETER
18.393225 | 42.113063 | L6 | L5 | .100 | .250 | GND | RC_PERIMETER
18.429999 | 41.714758 | L6 | L5 | .100 | .250 | GND | RC_PERIMETER
18.429999 | 41.314759 | L6 | L5 | .100 | .250 | GND | RC_PERIMETER
18.428340 | 40.914762 | L6 | L5 | .100 | .250 | GND | RC_PERIMETER
18.187182 | 40.595634 | L6 | L5 | .100 | .250 | GND | RC_PERIMETER
17.788004 | 40.570000 | L6 | L5 | .100 | .250 | GND | RC_PERIMETER
17.388004 | 40.570000 | L6 | L5 | .100 | .250 | GND | RC_PERIMETER
16.988005 | 40.570000 | L6 | L5 | .100 | .250 | GND | RC_PERIMETER
16.588006 | 40.570000 | L6 | L5 | .100 | .250 | GND | RC_PERIMETER
16.516236 | 40.176491 | L6 | L5 | .100 | .250 | GND | RC_PERIMETER
16.516236 | 39.776491 | L6 | L5 | .100 | .250 | GND | RC_PERIMETER
16.516236 | 39.376492 | L6 | L5 | .100 | .250 | GND | RC_PERIMETER
16.506081 | 38.976620 | L6 | L5 | .100 | .250 | GND | RC_PERIMETER
15.402207 | 38.688810 | L6 | L5 | .100 | .250 | GND | RC_PERIMETER
15.100694 | 38.951659 | L6 | L5 | .100 | .250 | GND | RC_PERIMETER
15.083762 | 39.351301 | L6 | L5 | .100 | .250 | GND | RC_PERIMETER
15.083762 | 39.751300 | L6 | L5 | .100 | .250 | GND | RC_PERIMETER
15.083762 | 40.151299 | L6 | L5 | .100 | .250 | GND | RC_PERIMETER
15.083762 | 40.551298 | L6 | L5 | .100 | .250 | GND | RC_PERIMETER
14.874446 | 40.892161 | L6 | L5 | .100 | .250 | GND | RC_PERIMETER
14.869998 | 41.292137 | L6 | L5 | .100 | .250 | GND | RC_PERIMETER
14.869998 | 41.692137 | L6 | L5 | .100 | .250 | GND | RC_PERIMETER
10.283764 | 49.241680 | L6 | L5 | .100 | .250 | GND | RC_PERIMETER
10.283764 | 49.641679 | L6 | L5 | .100 | .250 | GND | RC_PERIMETER
10.283764 | 50.041678 | L6 | L5 | .100 | .250 | GND | RC_PERIMETER
10.283764 | 50.441677 | L6 | L5 | .100 | .250 | GND | RC_PERIMETER
10.287833 | 50.841656 | L6 | L5 | .100 | .250 | GND | RC_PERIMETER
10.545722 | 51.147424 | L6 | L5 | .100 | .250 | GND | RC_PERIMETER
11.708270 | 50.863541 | L6 | L5 | .100 | .250 | GND | RC_PERIMETER
11.716240 | 50.463620 | L6 | L5 | .100 | .250 | GND | RC_PERIMETER
11.716240 | 50.063621 | L6 | L5 | .100 | .250 | GND | RC_PERIMETER
11.716240 | 49.663622 | L6 | L5 | .100 | .250 | GND | RC_PERIMETER
11.829537 | 49.280003 | L6 | L5 | .100 | .250 | GND | RC_PERIMETER
12.229536 | 49.280000 | L6 | L5 | .100 | .250 | GND | RC_PERIMETER
12.629535 | 49.280000 | L6 | L5 | .100 | .250 | GND | RC_PERIMETER
13.029535 | 49.280000 | L6 | L5 | .100 | .250 | GND | RC_PERIMETER
13.427126 | 49.236173 | L6 | L5 | .100 | .250 | GND | RC_PERIMETER
13.630003 | 48.891439 | L6 | L5 | .100 | .250 | GND | RC_PERIMETER
13.630003 | 48.491440 | L6 | L5 | .100 | .250 | GND | RC_PERIMETER
13.630003 | 48.091441 | L6 | L5 | .100 | .250 | GND | RC_PERIMETER
13.570519 | 47.695889 | L6 | L5 | .100 | .250 | GND | RC_PERIMETER
13.211266 | 47.519999 | L6 | L5 | .100 | .250 | GND | RC_PERIMETER
12.811267 | 47.519999 | L6 | L5 | .100 | .250 | GND | RC_PERIMETER
12.411268 | 47.519999 | L6 | L5 | .100 | .250 | GND | RC_PERIMETER
12.011269 | 47.519999 | L6 | L5 | .100 | .250 | GND | RC_PERIMETER
11.611270 | 47.520001 | L6 | L5 | .100 | .250 | GND | RC_PERIMETER
10.563271 | 47.520001 | L6 | L5 | .100 | .250 | GND | RC_PERIMETER
10.179581 | 47.633062 | L6 | L5 | .100 | .250 | GND | RC_PERIMETER
10.070000 | 48.017760 | L6 | L5 | .100 | .250 | GND | RC_PERIMETER
10.070000 | 48.417759 | L6 | L5 | .100 | .250 | GND | RC_PERIMETER
10.070000 | 48.817759 | L6 | L5 | .100 | .250 | GND | RC_PERIMETER
5.870001 | 48.900004 | L6 | L5 | .100 | .250 | GND | RC_PERIMETER
6.080544 | 49.240110 | L6 | L5 | .100 | .250 | GND | RC_PERIMETER
6.478549 | 49.280003 | L6 | L5 | .100 | .250 | GND | RC_PERIMETER
6.878549 | 49.280003 | L6 | L5 | .100 | .250 | GND | RC_PERIMETER
7.278548 | 49.280003 | L6 | L5 | .100 | .250 | GND | RC_PERIMETER
7.678547 | 49.280003 | L6 | L5 | .100 | .250 | GND | RC_PERIMETER
7.783764 | 49.665918 | L6 | L5 | .100 | .250 | GND | RC_PERIMETER
7.783764 | 50.065917 | L6 | L5 | .100 | .250 | GND | RC_PERIMETER
7.783764 | 50.465916 | L6 | L5 | .100 | .250 | GND | RC_PERIMETER
8.918407 | 51.157233 | L6 | L5 | .100 | .250 | GND | RC_PERIMETER
9.204952 | 50.878141 | L6 | L5 | .100 | .250 | GND | RC_PERIMETER
9.216238 | 50.478299 | L6 | L5 | .100 | .250 | GND | RC_PERIMETER
9.216238 | 50.078300 | L6 | L5 | .100 | .250 | GND | RC_PERIMETER
9.216238 | 49.678300 | L6 | L5 | .100 | .250 | GND | RC_PERIMETER
9.216238 | 49.278301 | L6 | L5 | .100 | .250 | GND | RC_PERIMETER
9.427982 | 48.938945 | L6 | L5 | .100 | .250 | GND | RC_PERIMETER
9.430001 | 48.538950 | L6 | L5 | .100 | .250 | GND | RC_PERIMETER
9.430001 | 48.138951 | L6 | L5 | .100 | .250 | GND | RC_PERIMETER
9.394876 | 47.740496 | L6 | L5 | .100 | .250 | GND | RC_PERIMETER
9.061018 | 47.520179 | L6 | L5 | .100 | .250 | GND | RC_PERIMETER
8.063019 | 47.520001 | L6 | L5 | .100 | .250 | GND | RC_PERIMETER
7.663020 | 47.520001 | L6 | L5 | .100 | .250 | GND | RC_PERIMETER
7.263021 | 47.520001 | L6 | L5 | .100 | .250 | GND | RC_PERIMETER
6.863022 | 47.520001 | L6 | L5 | .100 | .250 | GND | RC_PERIMETER
6.463022 | 47.520001 | L6 | L5 | .100 | .250 | GND | RC_PERIMETER
6.065868 | 47.567626 | L6 | L5 | .100 | .250 | GND | RC_PERIMETER
5.870001 | 47.916391 | L6 | L5 | .100 | .250 | GND | RC_PERIMETER
5.870001 | 48.316391 | L6 | L5 | .100 | .250 | GND | RC_PERIMETER
3.449998 | 30.120003 | L6 | L5 | .100 | .250 | GND | RC_PERIMETER
3.109892 | 30.330546 | L6 | L5 | .100 | .250 | GND | RC_PERIMETER
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

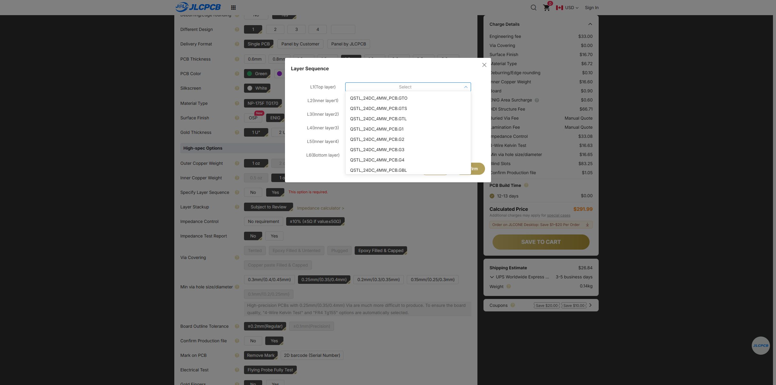
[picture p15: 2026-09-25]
QSTL_24DC_4MW_PCB/fabrication/JLCPCB_HDI_20260922/04_Uploaded_blind_drill_file.png

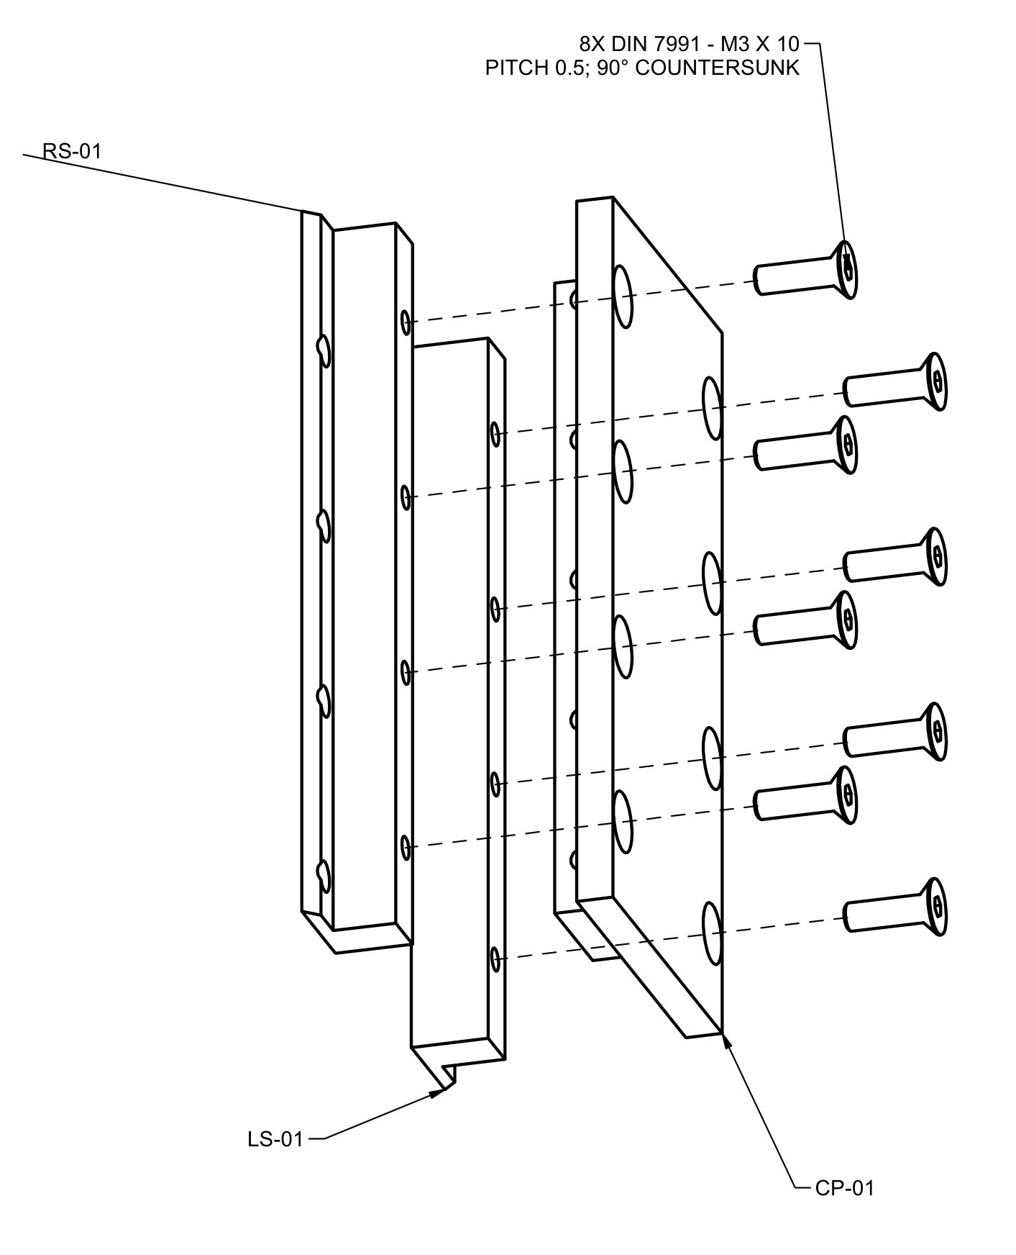
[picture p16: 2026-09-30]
QSTL_24DC_4MW_PCB/Mechanical_Assembly/Rod_Holder_Adapter_Drop8p5/Views_20260929/02_Plate_exploded_RevE.png

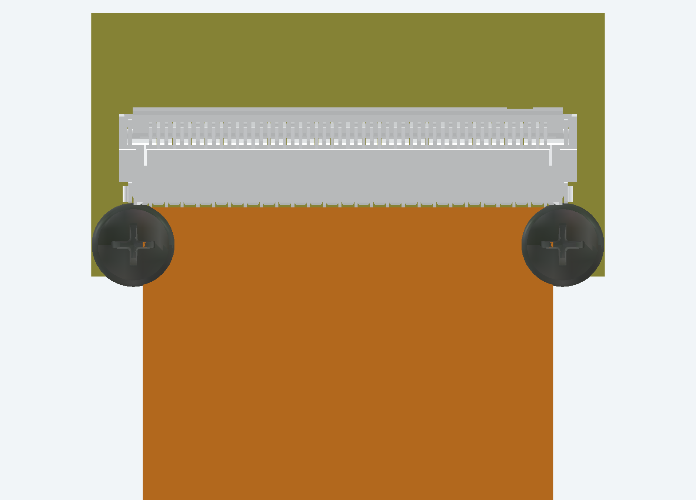
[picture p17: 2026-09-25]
QSTL_24DC_4MW_PCB/Mechanical_Assembly/ZIF_M1p6_Review/ZIF_M1p6_Round_Top.png

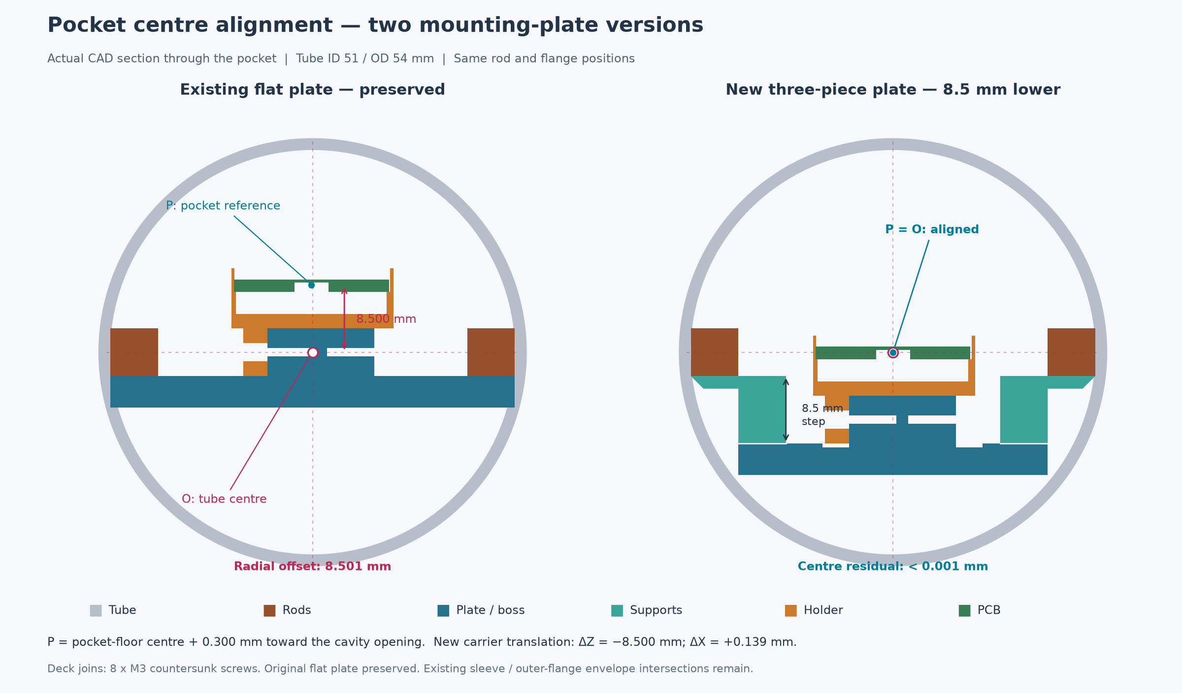
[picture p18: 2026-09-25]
QSTL_24DC_4MW_PCB/Mechanical_Assembly/Rod_Holder_Adapter_Drop8p5/Plate_versions_comparison.png

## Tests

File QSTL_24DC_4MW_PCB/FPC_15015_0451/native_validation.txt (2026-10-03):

REOPENED
UNROUTED_CONNECTIONS=0
SIGNAL_LAYER_COUNT=1
DRC_RETURNED_TRUE
COMPLETE

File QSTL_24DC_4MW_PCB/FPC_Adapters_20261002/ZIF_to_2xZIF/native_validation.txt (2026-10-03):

SAVED_AND_REOPENED=C:\JeonghyunPark\Workspace\QSTL_24DC_4MW_PCB\QSTL_24DC_4MW_PCB\FPC_Adapters_20261002\ZIF_to_2xZIF\ZIF_to_2xZIF.PcbDoc
PAD=C.51|MASK=0|PASTE=0
PAD=C.50|MASK=0|PASTE=0
PAD=C.49|MASK=0|PASTE=0
PAD=C.48|MASK=0|PASTE=0
PAD=C.47|MASK=0|PASTE=0
PAD=C.46|MASK=0|PASTE=0
PAD=C.45|MASK=0|PASTE=0
PAD=C.44|MASK=0|PASTE=0
PAD=C.43|MASK=0|PASTE=0
PAD=C.42|MASK=0|PASTE=0
PAD=C.41|MASK=0|PASTE=0
PAD=C.40|MASK=0|PASTE=0
PAD=C.39|MASK=0|PASTE=0
PAD=C.38|MASK=0|PASTE=0
PAD=C.37|MASK=0|PASTE=0
PAD=C.36|MASK=0|PASTE=0
PAD=C.35|MASK=0|PASTE=0
PAD=C.34|MASK=0|PASTE=0
PAD=C.33|MASK=0|PASTE=0
PAD=C.32|MASK=0|PASTE=0
PAD=C.31|MASK=0|PASTE=0
PAD=C.30|MASK=0|PASTE=0
PAD=C.29|MASK=0|PASTE=0
PAD=C.28|MASK=0|PASTE=0
PAD=C.27|MASK=0|PASTE=0
PAD=C.26|MASK=0|PASTE=0
PAD=C.25|MASK=0|PASTE=0
PAD=C.24|MASK=0|PASTE=0
PAD=C.23|MASK=0|PASTE=0
PAD=C.22|MASK=0|PASTE=0
PAD=C.21|MASK=0|PASTE=0
PAD=C.20|MASK=0|PASTE=0
PAD=C.19|MASK=0|PASTE=0
PAD=C.18|MASK=0|PASTE=0
PAD=C.17|MASK=0|PASTE=0
PAD=C.16|MASK=0|PASTE=0
PAD=C.15|MASK=0|PASTE=0
PAD=C.14|MASK=0|PASTE=0
PAD=C.13|MASK=0|PASTE=0
PAD=C.12|MASK=0|PASTE=0
PAD=C.11|MASK=0|PASTE=0
PAD=C.10|MASK=0|PASTE=0
PAD=C.9|MASK=0|PASTE=0
PAD=C.8|MASK=0|PASTE=0
PAD=C.7|MASK=0|PASTE=0
PAD=C.6|MASK=0|PASTE=0
PAD=C.5|MASK=0|PASTE=0
PAD=C.4|MASK=0|PASTE=0
PAD=C.3|MASK=0|PASTE=0
PAD=C.2|MASK=0|PASTE=0
PAD=C.1|MASK=0|PASTE=0
PAD=B.51|MASK=0|PASTE=0
PAD=A.51|MASK=0|PASTE=0
PAD=B.50|MASK=0|PASTE=0
PAD=A.50|MASK=0|PASTE=0
PAD=B.49|MASK=0|PASTE=0
PAD=A.49|MASK=0|PASTE=0
PAD=B.48|MASK=0|PASTE=0
PAD=A.48|MASK=0|PASTE=0
PAD=B.47|MASK=0|PASTE=0
PAD=A.47|MASK=0|PASTE=0
PAD=B.46|MASK=0|PASTE=0
PAD=A.46|MASK=0|PASTE=0
PAD=B.45|MASK=0|PASTE=0
PAD=A.45|MASK=0|PASTE=0
PAD=B.44|MASK=0|PASTE=0
PAD=A.44|MASK=0|PASTE=0
PAD=B.43|MASK=0|PASTE=0
PAD=A.43|MASK=0|PASTE=0
PAD=B.42|MASK=0|PASTE=0
PAD=A.42|MASK=0|PASTE=0
PAD=B.41|MASK=0|PASTE=0
PAD=A.41|MASK=0|PASTE=0
PAD=B.40|MASK=0|PASTE=0
PAD=A.40|MASK=0|PASTE=0
PAD=B.39|MASK=0|PASTE=0
PAD=A.39|MASK=0|PASTE=0
PAD=B.38|MASK=0|PASTE=0
PAD=A.38|MASK=0|PASTE=0
PAD=B.37|MASK=0|PASTE=0
PAD=A.37|MASK=0|PASTE=0
PAD=B.36|MASK=0|PASTE=0
PAD=A.36|MASK=0|PASTE=0
PAD=B.35|MASK=0|PASTE=0
PAD=A.35|MASK=0|PASTE=0
PAD=B.34|MASK=0|PASTE=0
PAD=A.34|MASK=0|PASTE=0
PAD=B.33|MASK=0|PASTE=0
PAD=A.33|MASK=0|PASTE=0
PAD=B.32|MASK=0|PASTE=0
PAD=A.32|MASK=0|PASTE=0
PAD=B.31|MASK=0|PASTE=0
PAD=A.31|MASK=0|PASTE=0
PAD=B.30|MASK=0|PASTE=0
PAD=A.30|MASK=0|PASTE=0
PAD=B.29|MASK=0|PASTE=0
PAD=A.29|MASK=0|PASTE=0
PAD=B.28|MASK=0|PASTE=0
PAD=A.28|MASK=0|PASTE=0
PAD=B.27|MASK=0|PASTE=0
PAD=A.27|MASK=0|PASTE=0
PAD=B.26|MASK=0|PASTE=0
PAD=A.26|MASK=0|PASTE=0
PAD=B.25|MASK=0|PASTE=0
PAD=A.25|MASK=0|PASTE=0
PAD=B.24|MASK=0|PASTE=0
PAD=A.24|MASK=0|PASTE=0
PAD=B.23|MASK=0|PASTE=0
PAD=A.23|MASK=0|PASTE=0
PAD=B.22|MASK=0|PASTE=0
PAD=A.22|MASK=0|PASTE=0
PAD=B.21|MASK=0|PASTE=0
PAD=A.21|MASK=0|PASTE=0
PAD=B.20|MASK=0|PASTE=0
PAD=A.20|MASK=0|PASTE=0
PAD=B.19|MASK=0|PASTE=0
PAD=A.19|MASK=0|PASTE=0
PAD=B.18|MASK=0|PASTE=0
PAD=A.18|MASK=0|PASTE=0
PAD=B.17|MASK=0|PASTE=0
PAD=A.17|MASK=0|PASTE=0
PAD=B.16|MASK=0|PASTE=0
PAD=A.16|MASK=0|PASTE=0
PAD=B.15|MASK=0|PASTE=0
PAD=A.15|MASK=0|PASTE=0
PAD=B.14|MASK=0|PASTE=0
PAD=A.14|MASK=0|PASTE=0
PAD=B.13|MASK=0|PASTE=0
PAD=A.13|MASK=0|PASTE=0
PAD=B.12|MASK=0|PASTE=0
PAD=A.12|MASK=0|PASTE=0
PAD=B.11|MASK=0|PASTE=0
PAD=A.11|MASK=0|PASTE=0
PAD=B.10|MASK=0|PASTE=0
PAD=A.10|MASK=0|PASTE=0
PAD=B.9|MASK=0|PASTE=0
PAD=A.9|MASK=0|PASTE=0
PAD=B.8|MASK=0|PASTE=0
PAD=A.8|MASK=0|PASTE=0
PAD=B.7|MASK=0|PASTE=0
PAD=A.7|MASK=0|PASTE=0
PAD=B.6|MASK=0|PASTE=0
PAD=A.6|MASK=0|PASTE=0
PAD=B.5|MASK=0|PASTE=0
PAD=A.5|MASK=0|PASTE=0
PAD=B.4|MASK=0|PASTE=0
PAD=A.4|MASK=0|PASTE=0
PAD=B.3|MASK=0|PASTE=0
PAD=A.3|MASK=0|PASTE=0
PAD=B.2|MASK=0|PASTE=0
PAD=A.2|MASK=0|PASTE=0
PAD=B.1|MASK=0|PASTE=0
PAD=A.1|MASK=0|PASTE=0
PAD_COUNT=153
PAD_PASTE_ENABLED=0
VIA_COUNT=51
VIA_TENTED_BOTH=0
VIA_PASTE_ENABLED=51
REBUILT_CONNECTION_COUNT=0
DRC_RETURNED_TRUE
COMPLETE

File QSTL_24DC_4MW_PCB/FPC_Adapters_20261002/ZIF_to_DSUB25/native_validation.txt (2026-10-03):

SAVED_AND_REOPENED=C:\JeonghyunPark\Workspace\QSTL_24DC_4MW_PCB\QSTL_24DC_4MW_PCB\FPC_Adapters_20261002\ZIF_to_DSUB25\ZIF_to_DSUB25.PcbDoc
PAD=A.51|MASK=0|PASTE=0
PAD=A.50|MASK=0|PASTE=0
PAD=A.49|MASK=0|PASTE=0
PAD=A.48|MASK=0|PASTE=0
PAD=A.47|MASK=0|PASTE=0
PAD=A.46|MASK=0|PASTE=0
PAD=A.45|MASK=0|PASTE=0
PAD=A.44|MASK=0|PASTE=0
PAD=A.43|MASK=0|PASTE=0
PAD=A.42|MASK=0|PASTE=0
PAD=A.41|MASK=0|PASTE=0
PAD=A.40|MASK=0|PASTE=0
PAD=A.39|MASK=0|PASTE=0
PAD=A.38|MASK=0|PASTE=0
PAD=A.37|MASK=0|PASTE=0
PAD=A.36|MASK=0|PASTE=0
PAD=A.35|MASK=0|PASTE=0
PAD=A.34|MASK=0|PASTE=0
PAD=A.33|MASK=0|PASTE=0
PAD=A.32|MASK=0|PASTE=0
PAD=A.31|MASK=0|PASTE=0
PAD=A.30|MASK=0|PASTE=0
PAD=A.29|MASK=0|PASTE=0
PAD=A.28|MASK=0|PASTE=0
PAD=A.27|MASK=0|PASTE=0
PAD=A.26|MASK=0|PASTE=0
PAD=A.25|MASK=0|PASTE=0
PAD=A.24|MASK=0|PASTE=0
PAD=A.23|MASK=0|PASTE=0
PAD=A.22|MASK=0|PASTE=0
PAD=A.21|MASK=0|PASTE=0
PAD=A.20|MASK=0|PASTE=0
PAD=A.19|MASK=0|PASTE=0
PAD=A.18|MASK=0|PASTE=0
PAD=A.17|MASK=0|PASTE=0
PAD=A.16|MASK=0|PASTE=0
PAD=A.15|MASK=0|PASTE=0
PAD=A.14|MASK=0|PASTE=0
PAD=A.13|MASK=0|PASTE=0
PAD=A.12|MASK=0|PASTE=0
PAD=A.11|MASK=0|PASTE=0
PAD=A.10|MASK=0|PASTE=0
PAD=A.9|MASK=0|PASTE=0
PAD=A.8|MASK=0|PASTE=0
PAD=A.7|MASK=0|PASTE=0
PAD=A.6|MASK=0|PASTE=0
PAD=A.5|MASK=0|PASTE=0
PAD=A.4|MASK=0|PASTE=0
PAD=A.3|MASK=0|PASTE=0
PAD=A.2|MASK=0|PASTE=0
PAD=A.1|MASK=0|PASTE=0
PAD=J1.BL2|MASK=0.05|PASTE=0
PAD=J1.BL1|MASK=0.05|PASTE=0
PAD=J1.13|MASK=0.05|PASTE=0
PAD=J1.25|MASK=0.05|PASTE=0
PAD=J1.12|MASK=0.05|PASTE=0
PAD=J1.24|MASK=0.05|PASTE=0
PAD=J1.11|MASK=0.05|PASTE=0
PAD=J1.23|MASK=0.05|PASTE=0
PAD=J1.10|MASK=0.05|PASTE=0
PAD=J1.22|MASK=0.05|PASTE=0
PAD=J1.9|MASK=0.05|PASTE=0
PAD=J1.21|MASK=0.05|PASTE=0
PAD=J1.8|MASK=0.05|PASTE=0
PAD=J1.20|MASK=0.05|PASTE=0
PAD=J1.7|MASK=0.05|PASTE=0
PAD=J1.19|MASK=0.05|PASTE=0
PAD=J1.6|MASK=0.05|PASTE=0
PAD=J1.18|MASK=0.05|PASTE=0
PAD=J1.5|MASK=0.05|PASTE=0
PAD=J1.17|MASK=0.05|PASTE=0
PAD=J1.4|MASK=0.05|PASTE=0
PAD=J1.16|MASK=0.05|PASTE=0
PAD=J1.3|MASK=0.05|PASTE=0
PAD=J1.15|MASK=0.05|PASTE=0
PAD=J1.2|MASK=0.05|PASTE=0
PAD=J1.14|MASK=0.05|PASTE=0
PAD=J1.1|MASK=0.05|PASTE=0
PAD_COUNT=78
PAD_PASTE_ENABLED=0
VIA_COUNT=12
VIA_TENTED_BOTH=0
VIA_PASTE_ENABLED=12
REBUILT_CONNECTION_COUNT=0
DRC_RETURNED_TRUE
COMPLETE

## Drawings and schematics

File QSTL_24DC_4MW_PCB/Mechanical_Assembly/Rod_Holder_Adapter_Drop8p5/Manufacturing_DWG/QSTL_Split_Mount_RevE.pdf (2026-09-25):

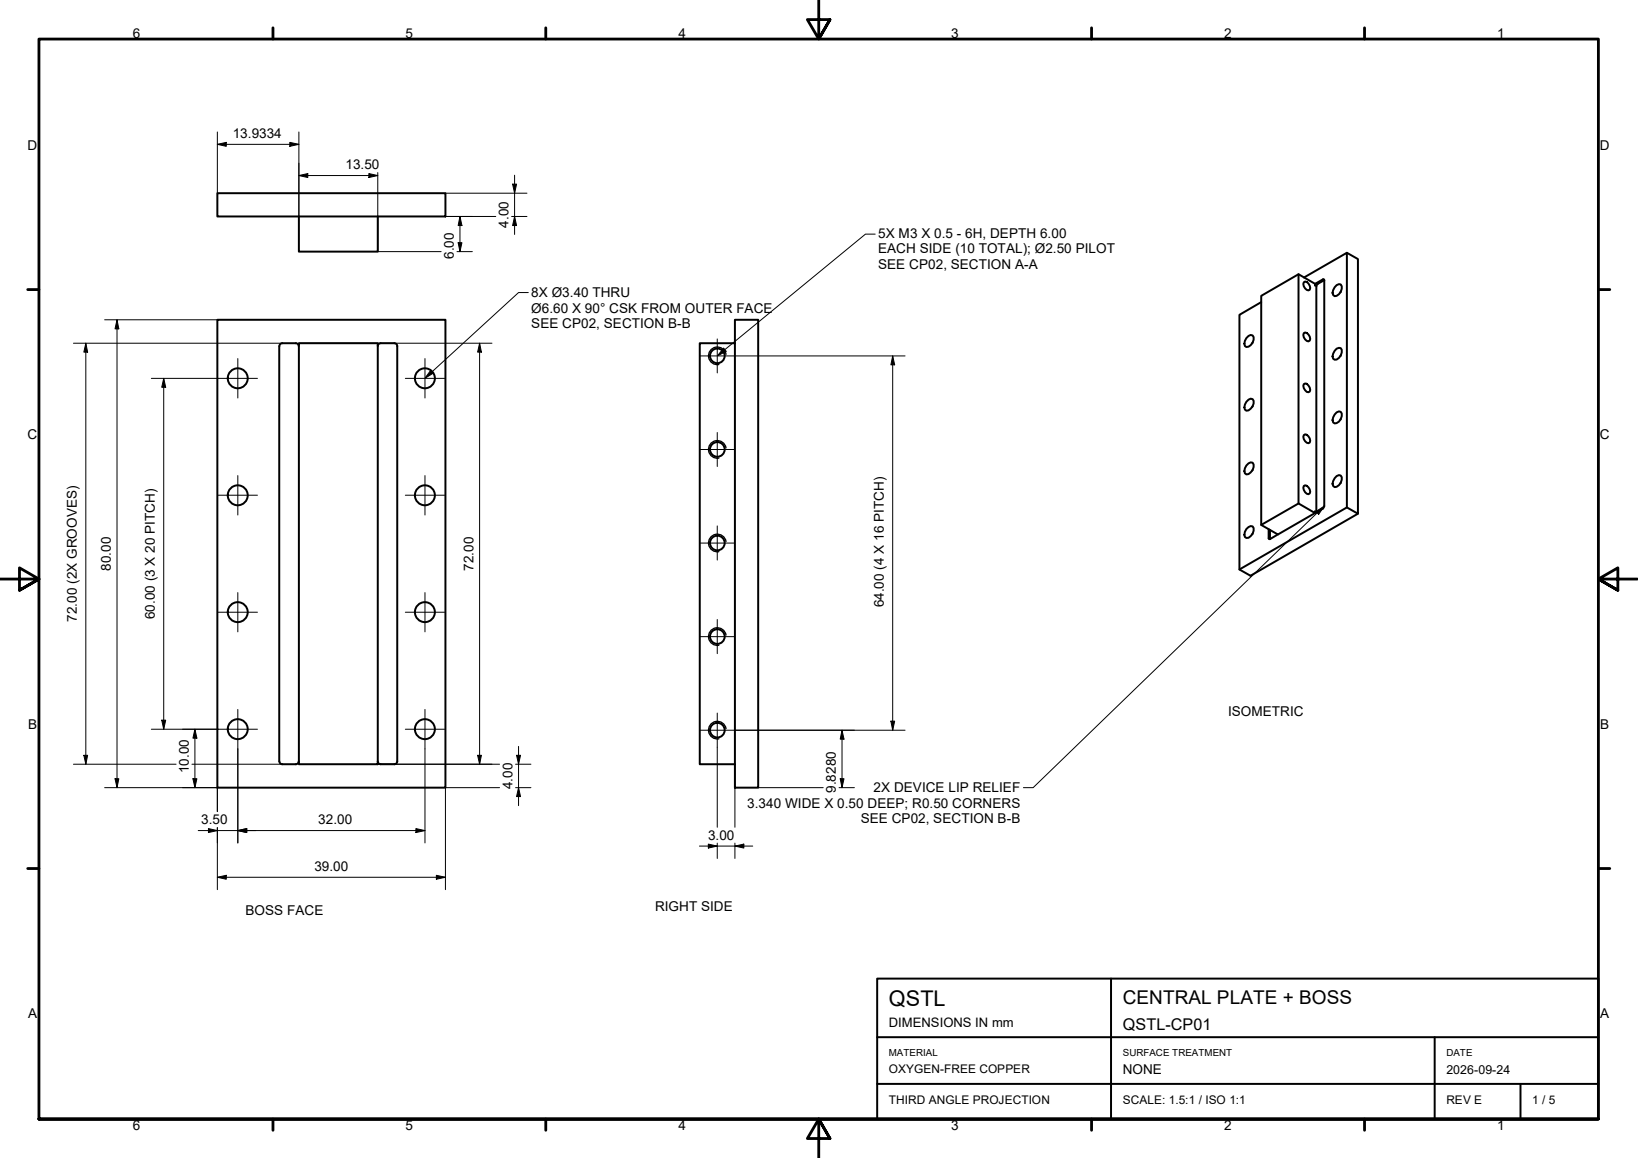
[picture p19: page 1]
BOSS FACE; RIGHT SIDE; SEE CP02, SECTION B-B

5X M3 X 0.5 - 6H, DEPTH 6.00
EACH SIDE (10 TOTAL); Ø2.50 PILOT
SEE CP02, SECTION A-A

8X Ø3.40 THRU
Ø6.60 X 90° CSK FROM OUTER FACE
SEE CP02, SECTION B-B

2X DEVICE LIP RELIEF

3.340 WIDE X 0.50 DEEP; R0.50 CORNERS

QSTL DIMENSIONS IN mm | CENTRAL PLATE + BOSS QSTL-CP01

MATERIAL OXYGEN-FREE COPPER | SURFACE TREATMENT NONE | DATE 2026-09-24

THIRD ANGLE PROJECTION | SCALE: 1.5:1 / ISO 1:1 | REV E | 1 / 5

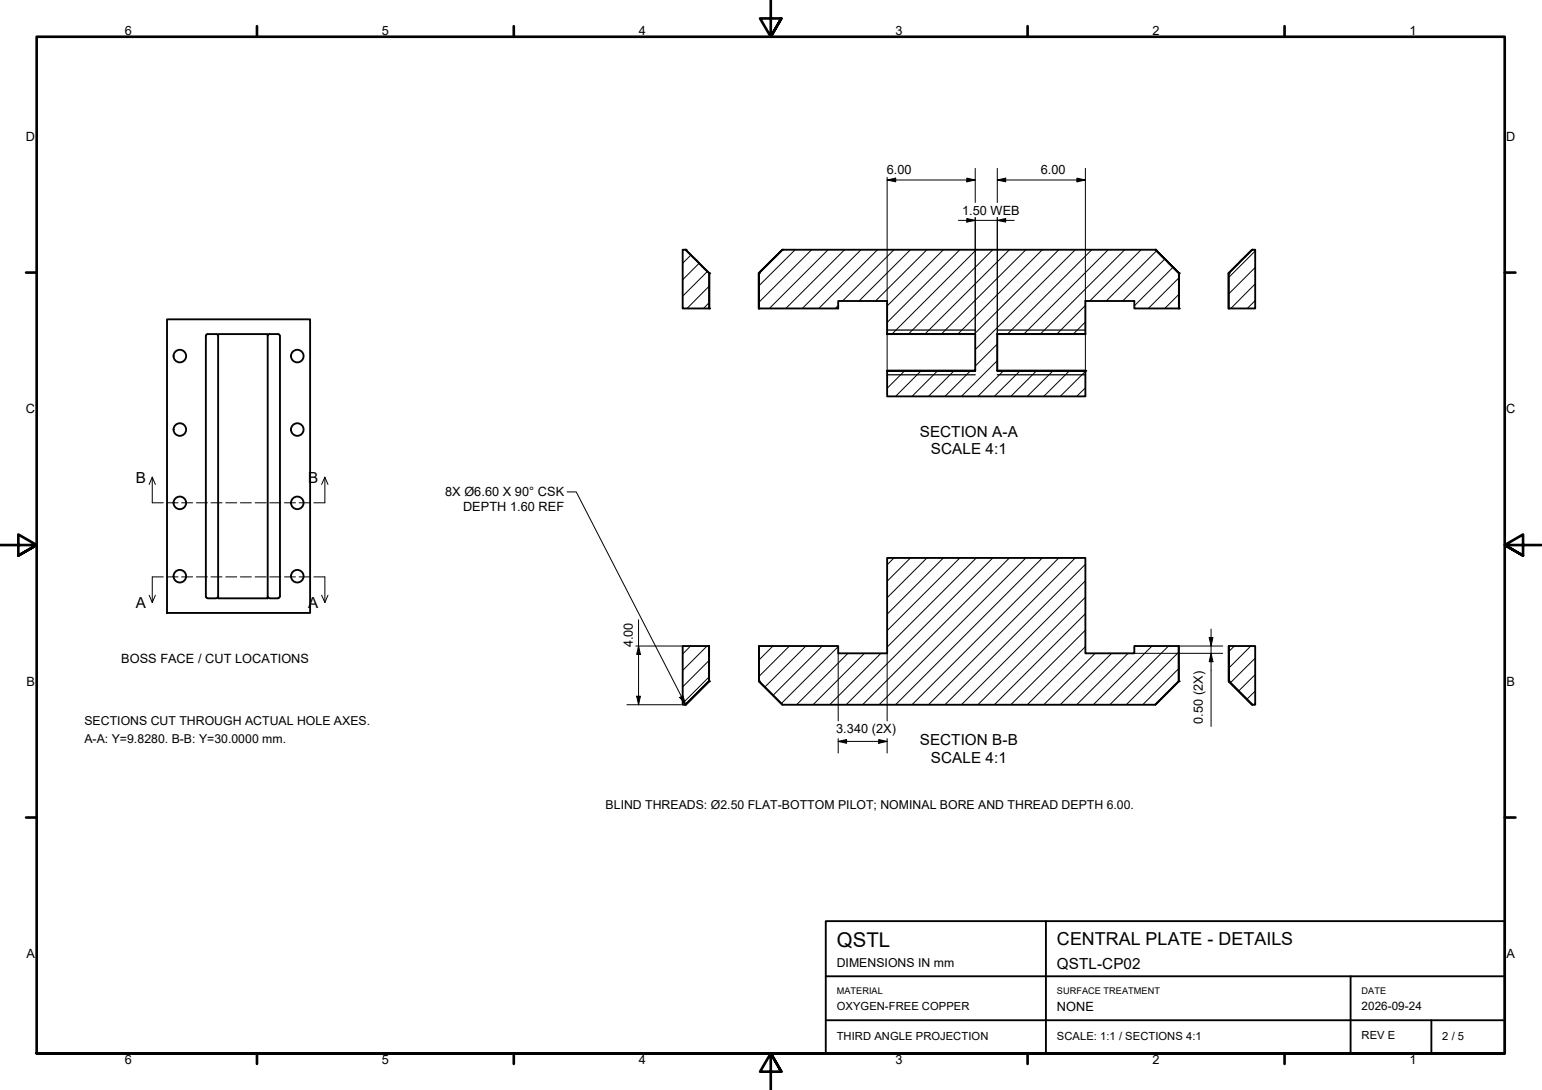
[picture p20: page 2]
SECTION A-A SCALE 4:1; SECTION B-B SCALE 4:1; 1.50 WEB; 8X Ø6.60 X 90° CSK DEPTH 1.60 REF

BOSS FACE / CUT LOCATIONS

SECTIONS CUT THROUGH ACTUAL HOLE AXES.

BLIND THREADS: Ø2.50 FLAT-BOTTOM PILOT; NOMINAL BORE AND THREAD DEPTH 6.00.

QSTL DIMENSIONS IN mm | CENTRAL PLATE - DETAILS QSTL-CP02

MATERIAL | SURFACE TREATMENT | DATE

THIRD ANGLE PROJECTION | SCALE: 1:1 / SECTIONS 4:1 | REV E | 2 / 5

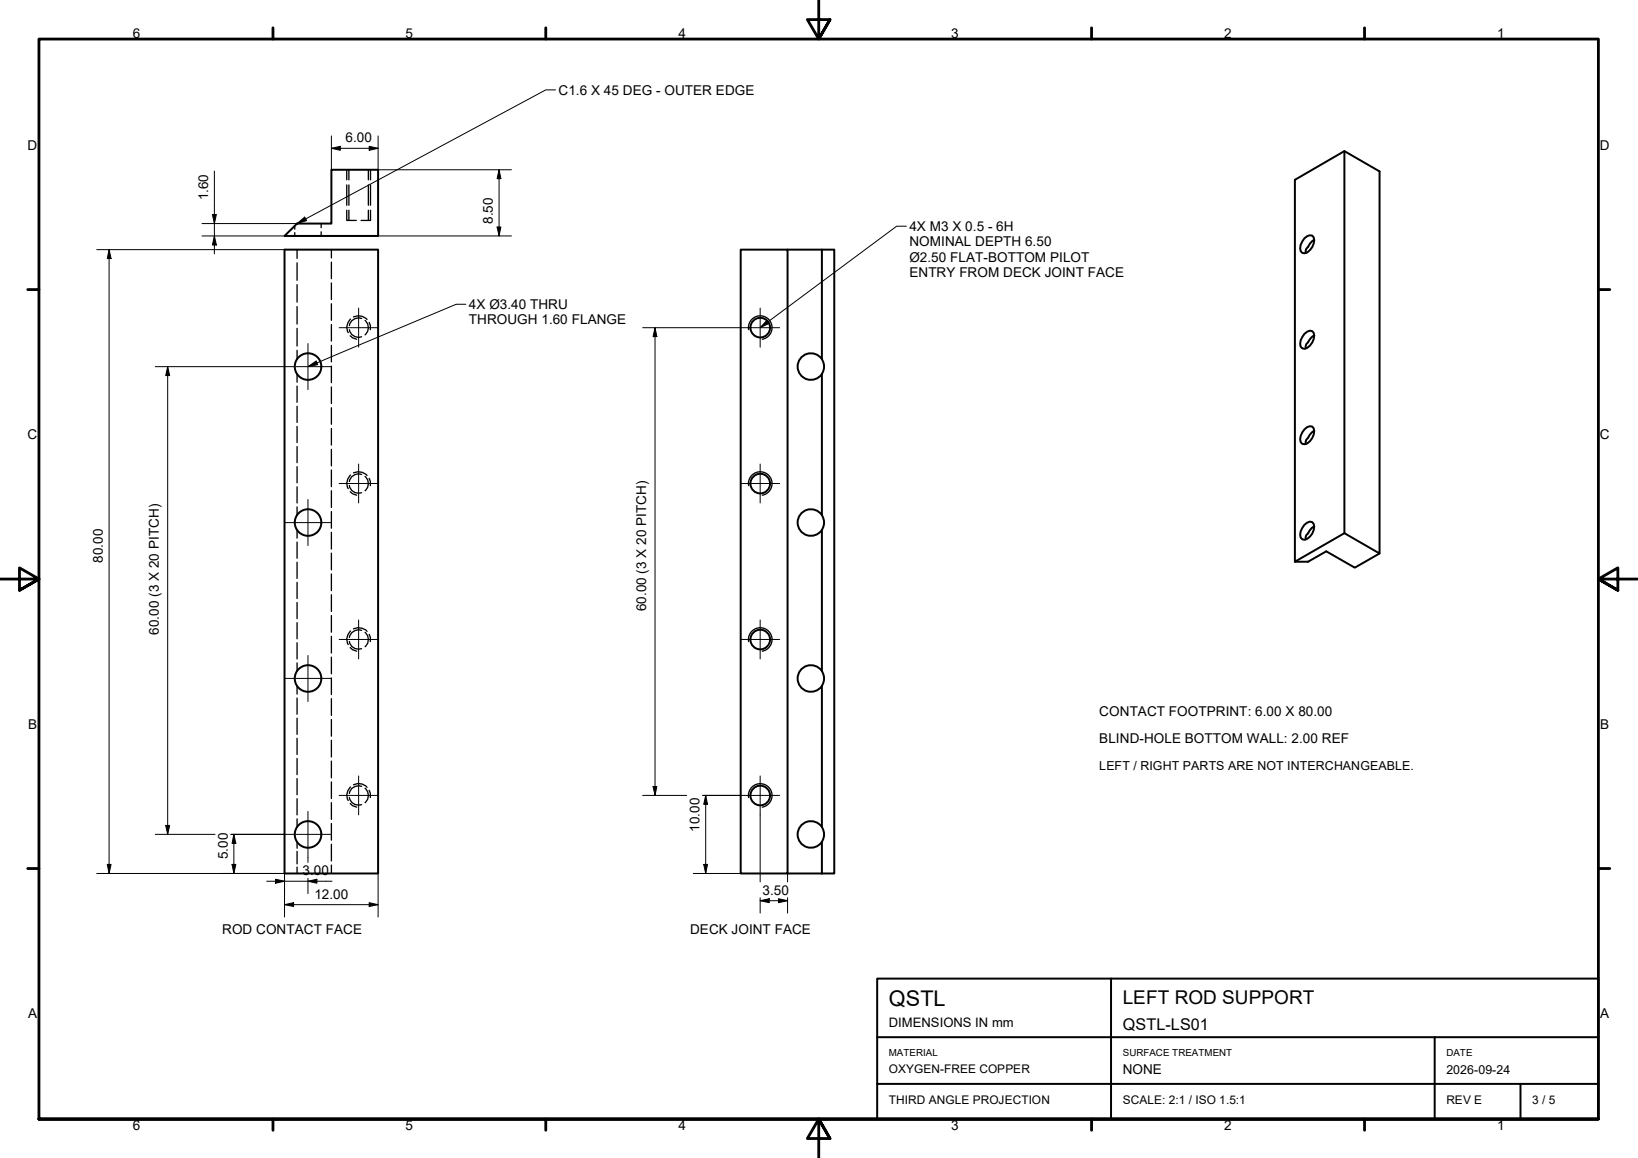
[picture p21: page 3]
4X Ø3.40 THRU THROUGH 1.60 FLANGE; ROD CONTACT FACE; DECK JOINT FACE; CONTACT FOOTPRINT: 6.00 X 80.00

C1.6 X 45 DEG - OUTER EDGE

NOMINAL DEPTH 6.50
Ø2.50 FLAT-BOTTOM PILOT
ENTRY FROM DECK JOINT FACE

BLIND-HOLE BOTTOM WALL: 2.00 REF

LEFT / RIGHT PARTS ARE NOT INTERCHANGEABLE.

QSTL DIMENSIONS IN mm | LEFT ROD SUPPORT QSTL-LS01

MATERIAL | SURFACE TREATMENT | DATE

THIRD ANGLE PROJECTION | SCALE: 2:1 / ISO 1.5:1 | REV E | 3 / 5

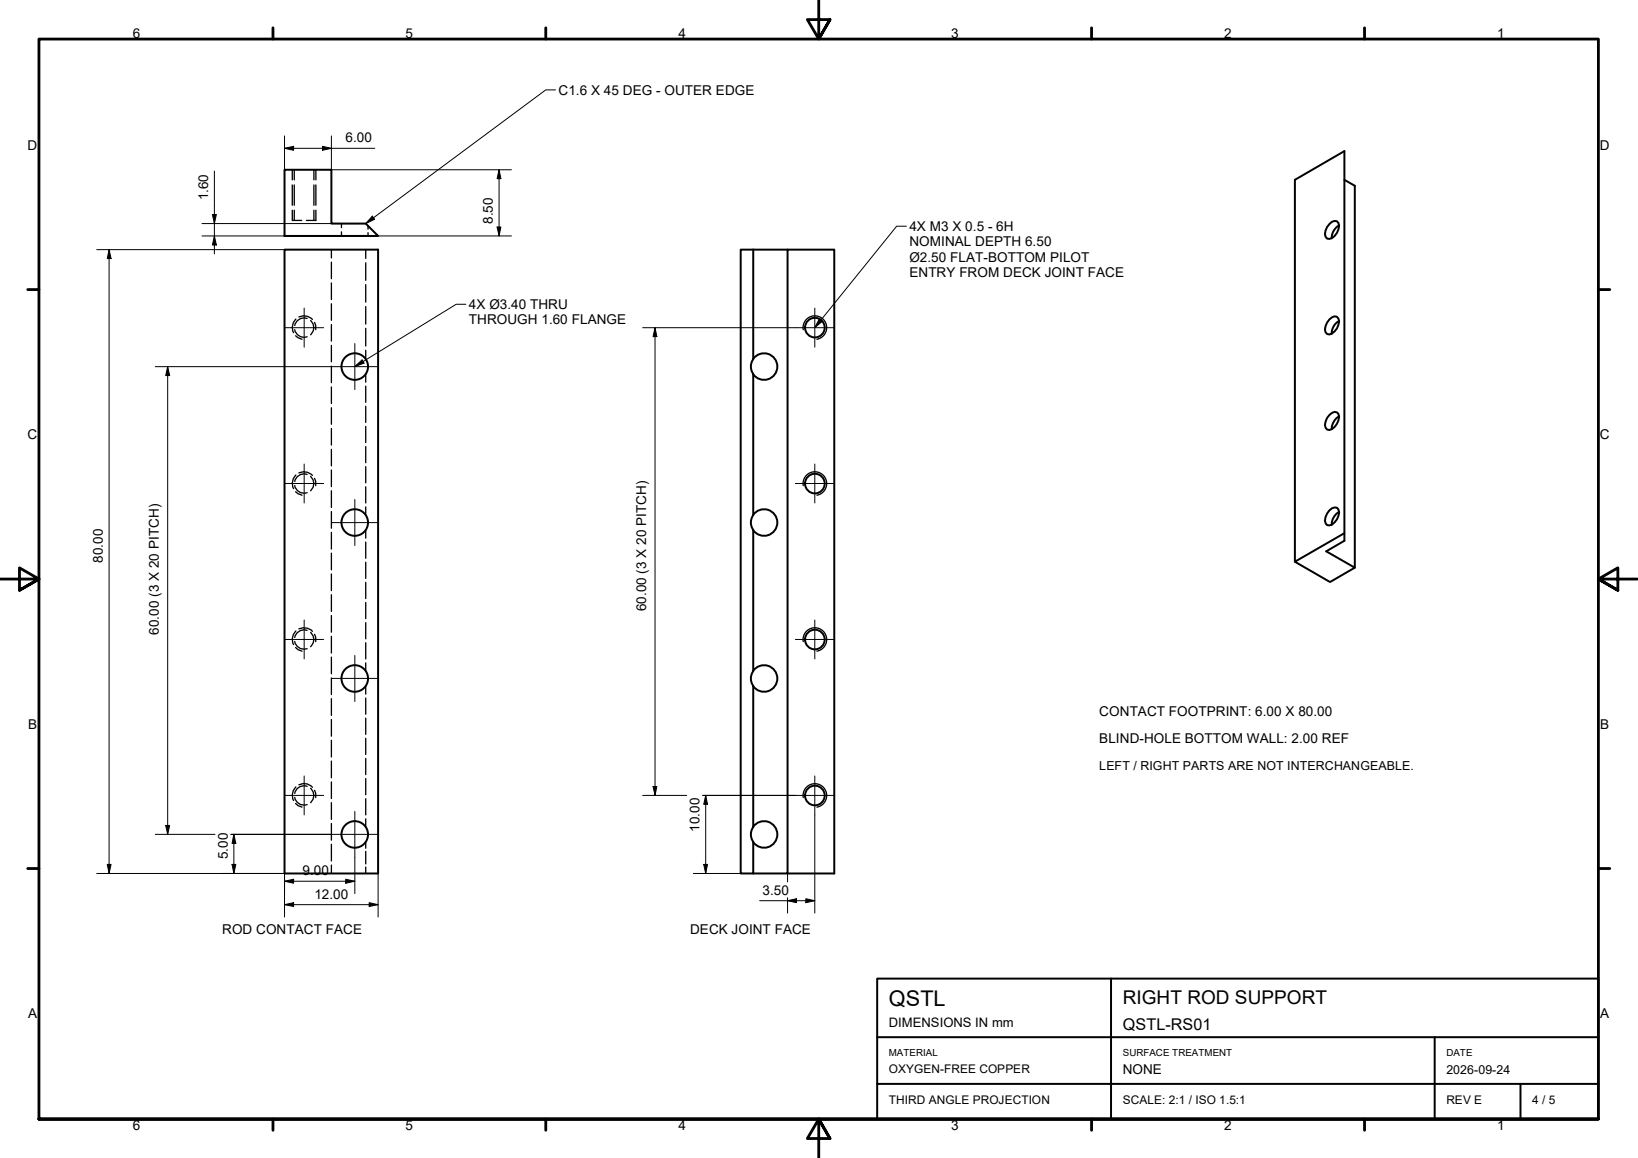
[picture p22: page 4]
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

C1.6 X 45 DEG - OUTER EDGE

NOMINAL DEPTH 6.50
Ø2.50 FLAT-BOTTOM PILOT
ENTRY FROM DECK JOINT FACE

BLIND-HOLE BOTTOM WALL: 2.00 REF

LEFT / RIGHT PARTS ARE NOT INTERCHANGEABLE.

QSTL DIMENSIONS IN mm | RIGHT ROD SUPPORT QSTL-RS01

MATERIAL | SURFACE TREATMENT | DATE

THIRD ANGLE PROJECTION | SCALE: 2:1 / ISO 1.5:1 | REV E | 4 / 5

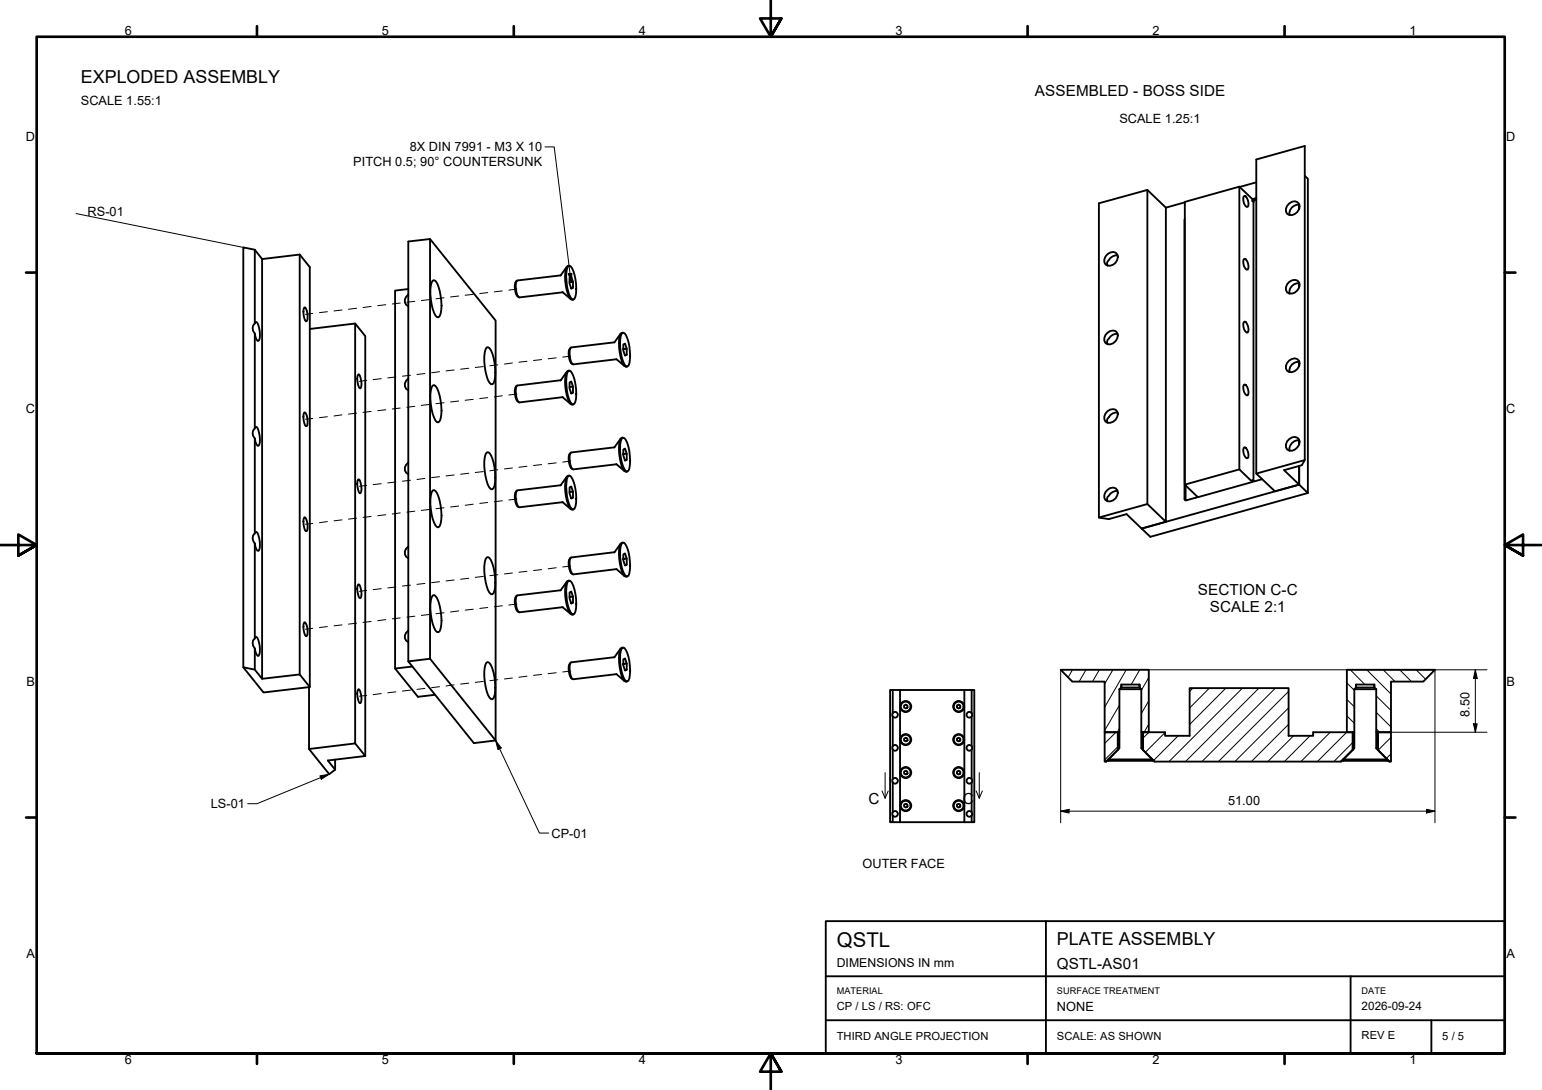
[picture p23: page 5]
SECTION C-C SCALE 2:1; EXPLODED ASSEMBLY; SCALE 1.55:1; 8X DIN 7991 - M3 X 10 PITCH 0.5; 90° COUNTERSUNK; SCALE 1.25:1; OUTER FACE

ASSEMBLED - BOSS SIDE

QSTL DIMENSIONS IN mm | PLATE ASSEMBLY QSTL-AS01

MATERIAL CP / LS / RS: OFC | SURFACE TREATMENT | DATE

THIRD ANGLE PROJECTION | SCALE: AS SHOWN | REV E | 5 / 5

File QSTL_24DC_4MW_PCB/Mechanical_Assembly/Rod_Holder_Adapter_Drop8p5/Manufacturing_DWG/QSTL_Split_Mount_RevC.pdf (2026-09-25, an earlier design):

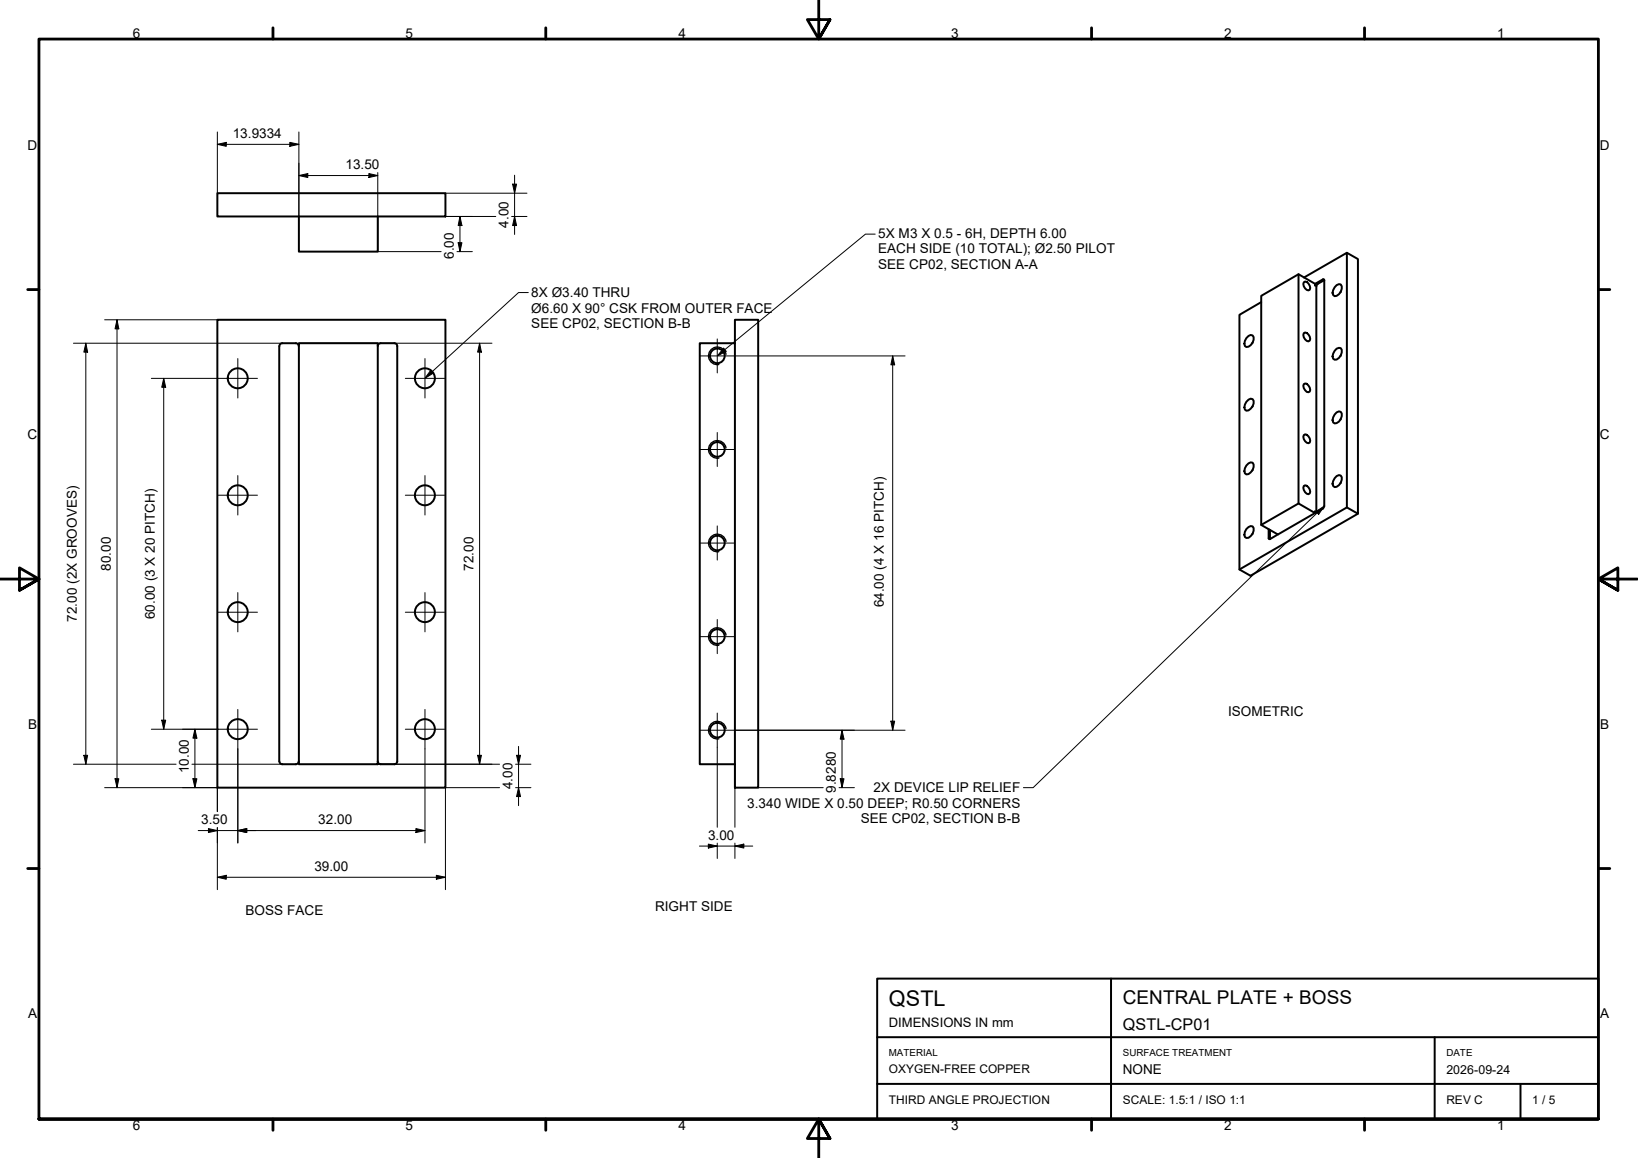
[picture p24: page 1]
BOSS FACE; RIGHT SIDE; SEE CP02, SECTION B-B

5X M3 X 0.5 - 6H, DEPTH 6.00
EACH SIDE (10 TOTAL); Ø2.50 PILOT
SEE CP02, SECTION A-A

8X Ø3.40 THRU
Ø6.60 X 90° CSK FROM OUTER FACE
SEE CP02, SECTION B-B

2X DEVICE LIP RELIEF

3.340 WIDE X 0.50 DEEP; R0.50 CORNERS

QSTL DIMENSIONS IN mm | CENTRAL PLATE + BOSS QSTL-CP01

MATERIAL OXYGEN-FREE COPPER | SURFACE TREATMENT NONE | DATE 2026-09-24

THIRD ANGLE PROJECTION | SCALE: 1.5:1 / ISO 1:1 | REV C | 1 / 5

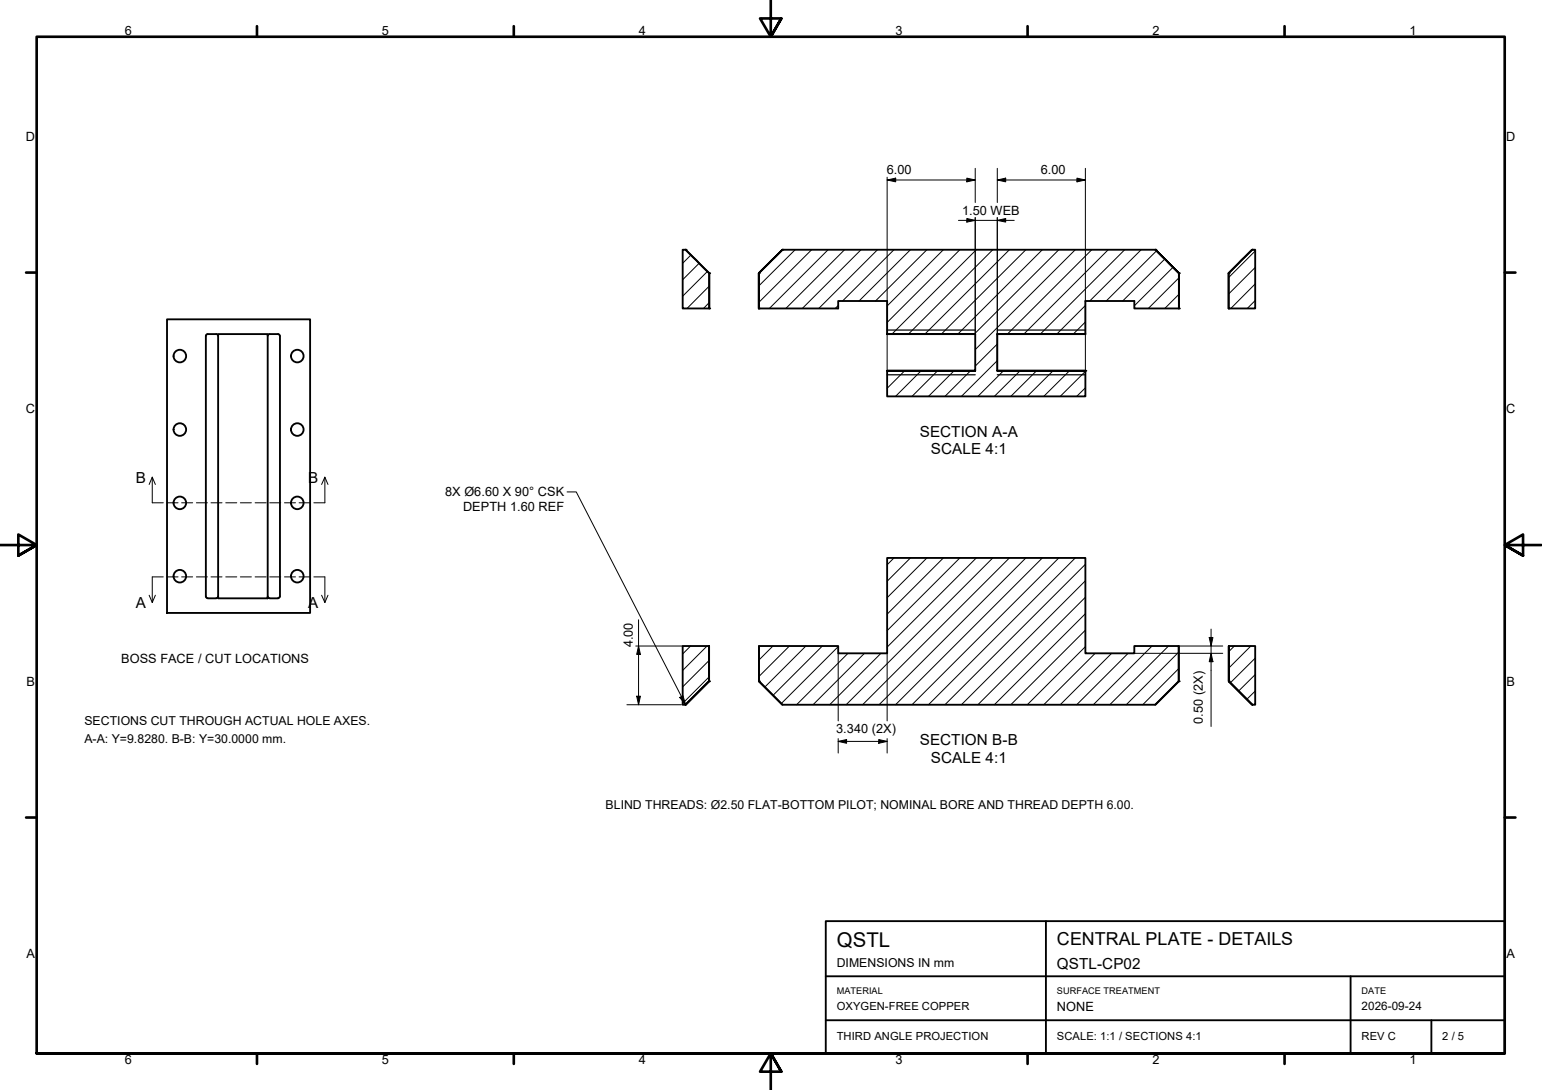
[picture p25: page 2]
SECTION A-A SCALE 4:1; SECTION B-B SCALE 4:1; 1.50 WEB; 8X Ø6.60 X 90° CSK DEPTH 1.60 REF

BOSS FACE / CUT LOCATIONS

SECTIONS CUT THROUGH ACTUAL HOLE AXES.

BLIND THREADS: Ø2.50 FLAT-BOTTOM PILOT; NOMINAL BORE AND THREAD DEPTH 6.00.

QSTL DIMENSIONS IN mm | CENTRAL PLATE - DETAILS QSTL-CP02

MATERIAL | SURFACE TREATMENT | DATE

THIRD ANGLE PROJECTION | SCALE: 1:1 / SECTIONS 4:1 | REV C | 2 / 5

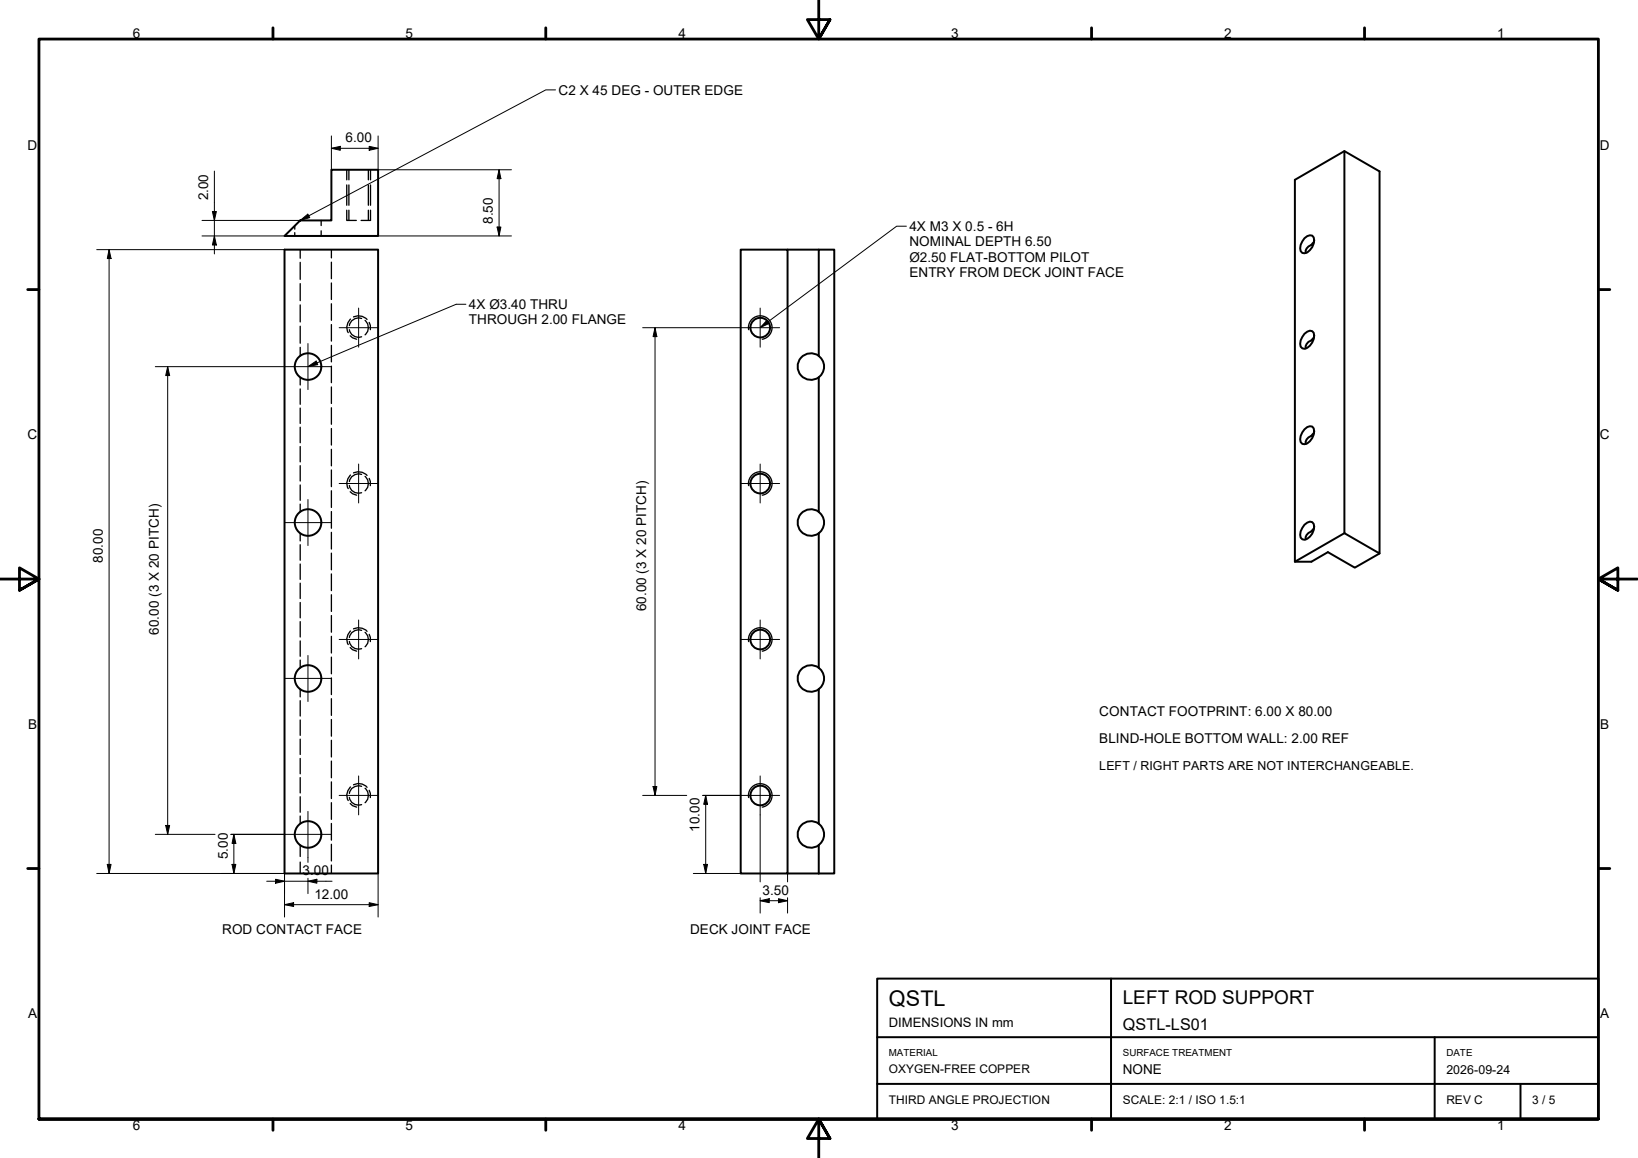
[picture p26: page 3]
4X Ø3.40 THRU THROUGH 2.00 FLANGE; ROD CONTACT FACE; DECK JOINT FACE; CONTACT FOOTPRINT: 6.00 X 80.00

C2 X 45 DEG - OUTER EDGE

NOMINAL DEPTH 6.50
Ø2.50 FLAT-BOTTOM PILOT
ENTRY FROM DECK JOINT FACE

BLIND-HOLE BOTTOM WALL: 2.00 REF

LEFT / RIGHT PARTS ARE NOT INTERCHANGEABLE.

QSTL DIMENSIONS IN mm | LEFT ROD SUPPORT QSTL-LS01

MATERIAL | SURFACE TREATMENT | DATE

THIRD ANGLE PROJECTION | SCALE: 2:1 / ISO 1.5:1 | REV C | 3 / 5

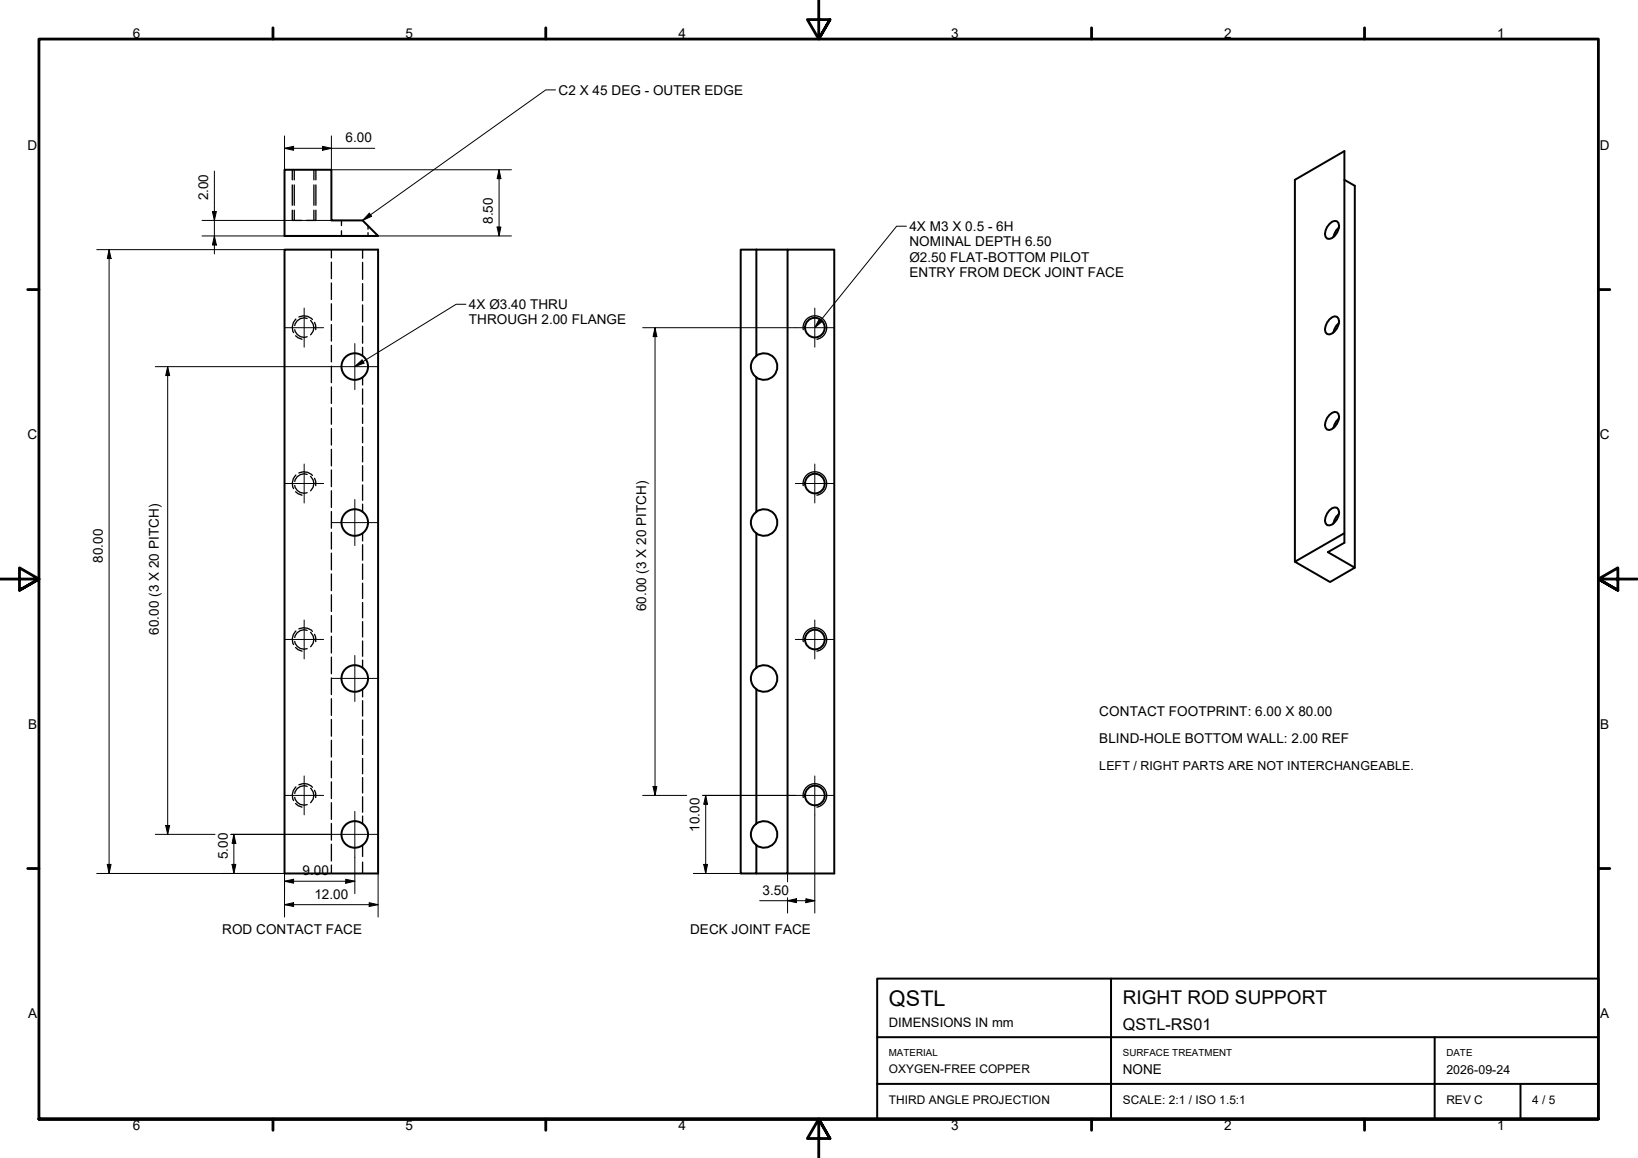
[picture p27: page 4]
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

C2 X 45 DEG - OUTER EDGE

NOMINAL DEPTH 6.50
Ø2.50 FLAT-BOTTOM PILOT
ENTRY FROM DECK JOINT FACE

BLIND-HOLE BOTTOM WALL: 2.00 REF

LEFT / RIGHT PARTS ARE NOT INTERCHANGEABLE.

QSTL DIMENSIONS IN mm | RIGHT ROD SUPPORT QSTL-RS01

MATERIAL | SURFACE TREATMENT | DATE

THIRD ANGLE PROJECTION | SCALE: 2:1 / ISO 1.5:1 | REV C | 4 / 5

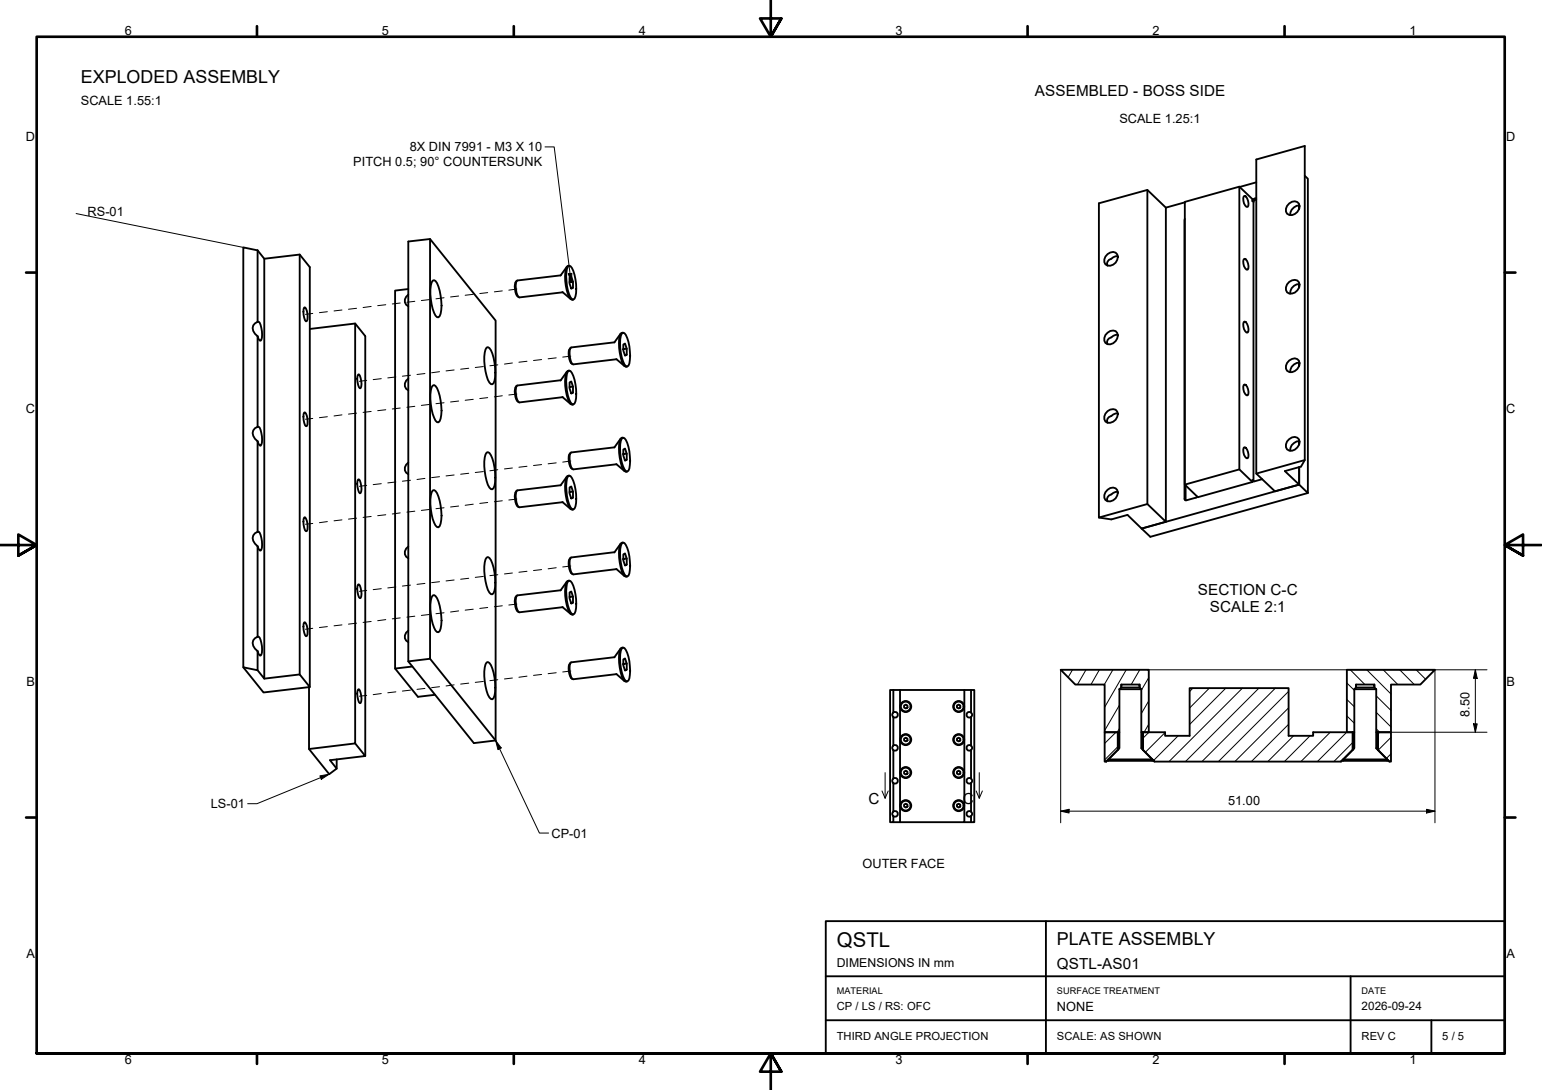
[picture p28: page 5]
SECTION C-C SCALE 2:1; EXPLODED ASSEMBLY; SCALE 1.55:1; 8X DIN 7991 - M3 X 10 PITCH 0.5; 90° COUNTERSUNK; SCALE 1.25:1; OUTER FACE

ASSEMBLED - BOSS SIDE

QSTL DIMENSIONS IN mm | PLATE ASSEMBLY QSTL-AS01

MATERIAL CP / LS / RS: OFC | SURFACE TREATMENT | DATE

THIRD ANGLE PROJECTION | SCALE: AS SHOWN | REV C | 5 / 5

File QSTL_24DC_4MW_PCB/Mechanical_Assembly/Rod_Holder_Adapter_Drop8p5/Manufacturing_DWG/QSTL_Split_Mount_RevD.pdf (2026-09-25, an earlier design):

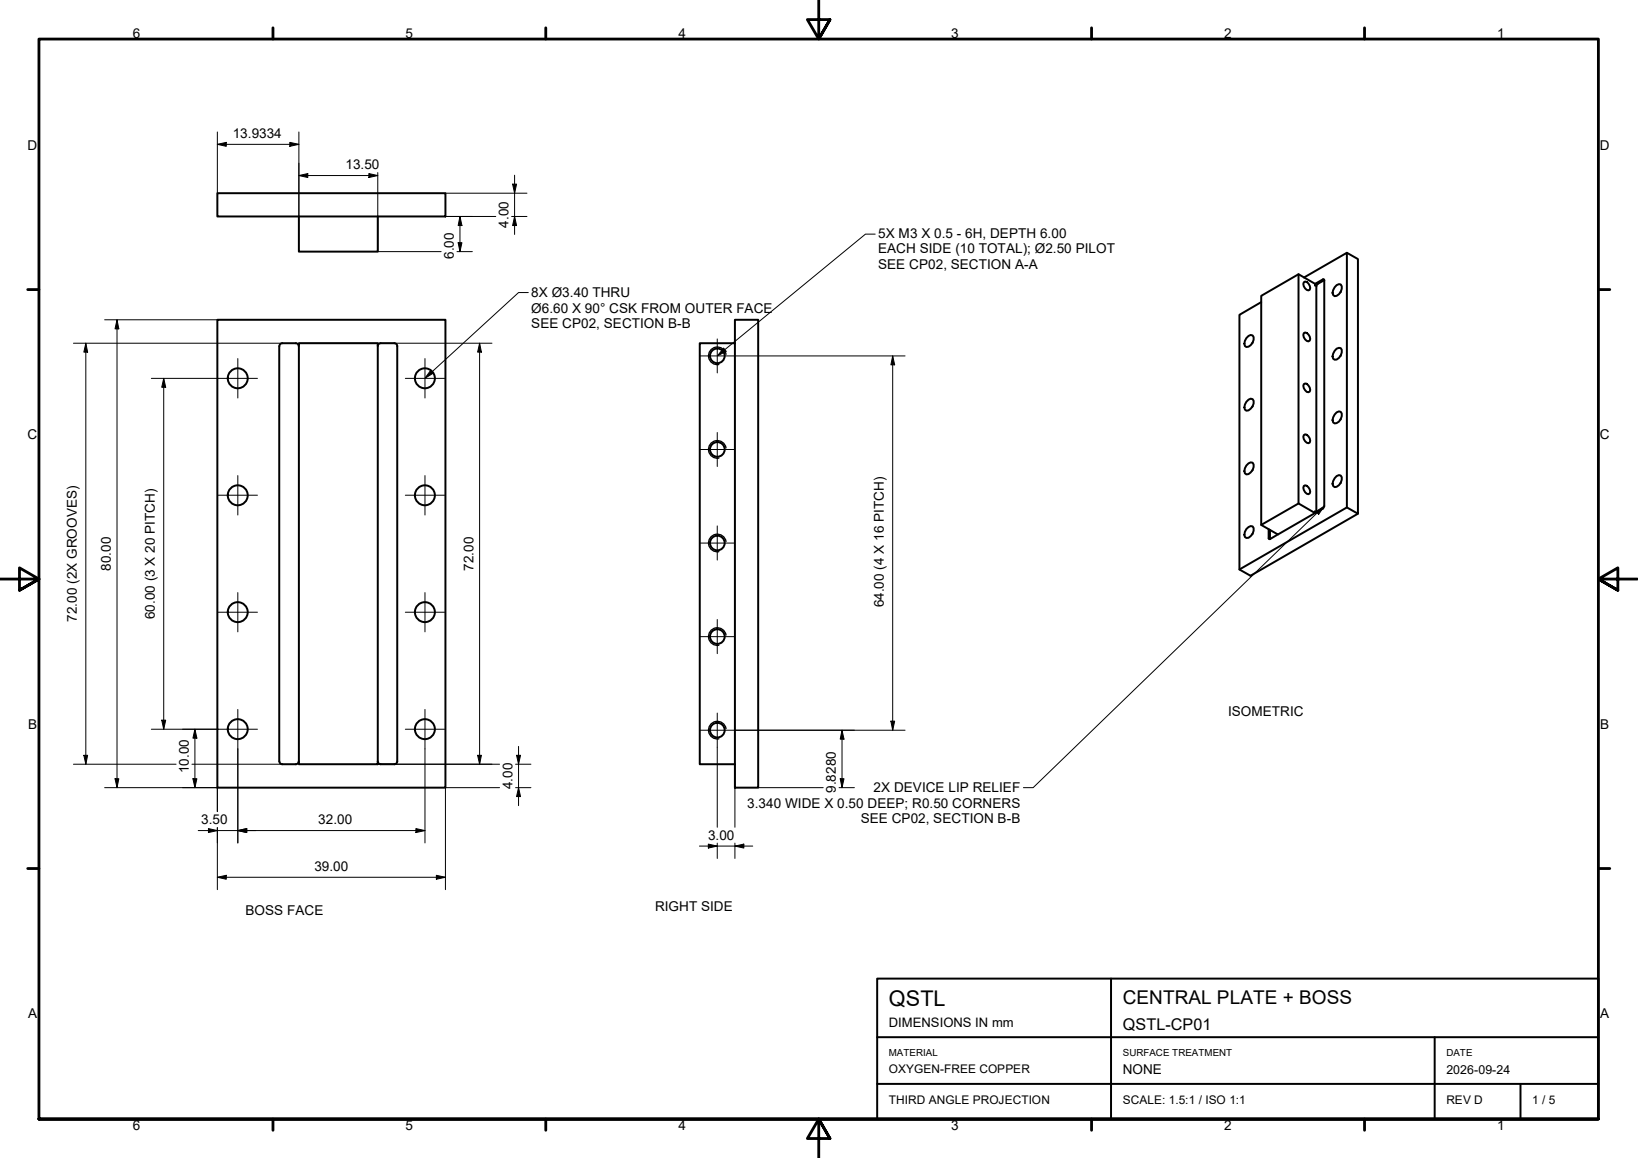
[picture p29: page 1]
BOSS FACE; RIGHT SIDE; SEE CP02, SECTION B-B

5X M3 X 0.5 - 6H, DEPTH 6.00
EACH SIDE (10 TOTAL); Ø2.50 PILOT
SEE CP02, SECTION A-A

8X Ø3.40 THRU
Ø6.60 X 90° CSK FROM OUTER FACE
SEE CP02, SECTION B-B

2X DEVICE LIP RELIEF

3.340 WIDE X 0.50 DEEP; R0.50 CORNERS

QSTL DIMENSIONS IN mm | CENTRAL PLATE + BOSS QSTL-CP01

MATERIAL OXYGEN-FREE COPPER | SURFACE TREATMENT NONE | DATE 2026-09-24

THIRD ANGLE PROJECTION | SCALE: 1.5:1 / ISO 1:1 | REV D | 1 / 5

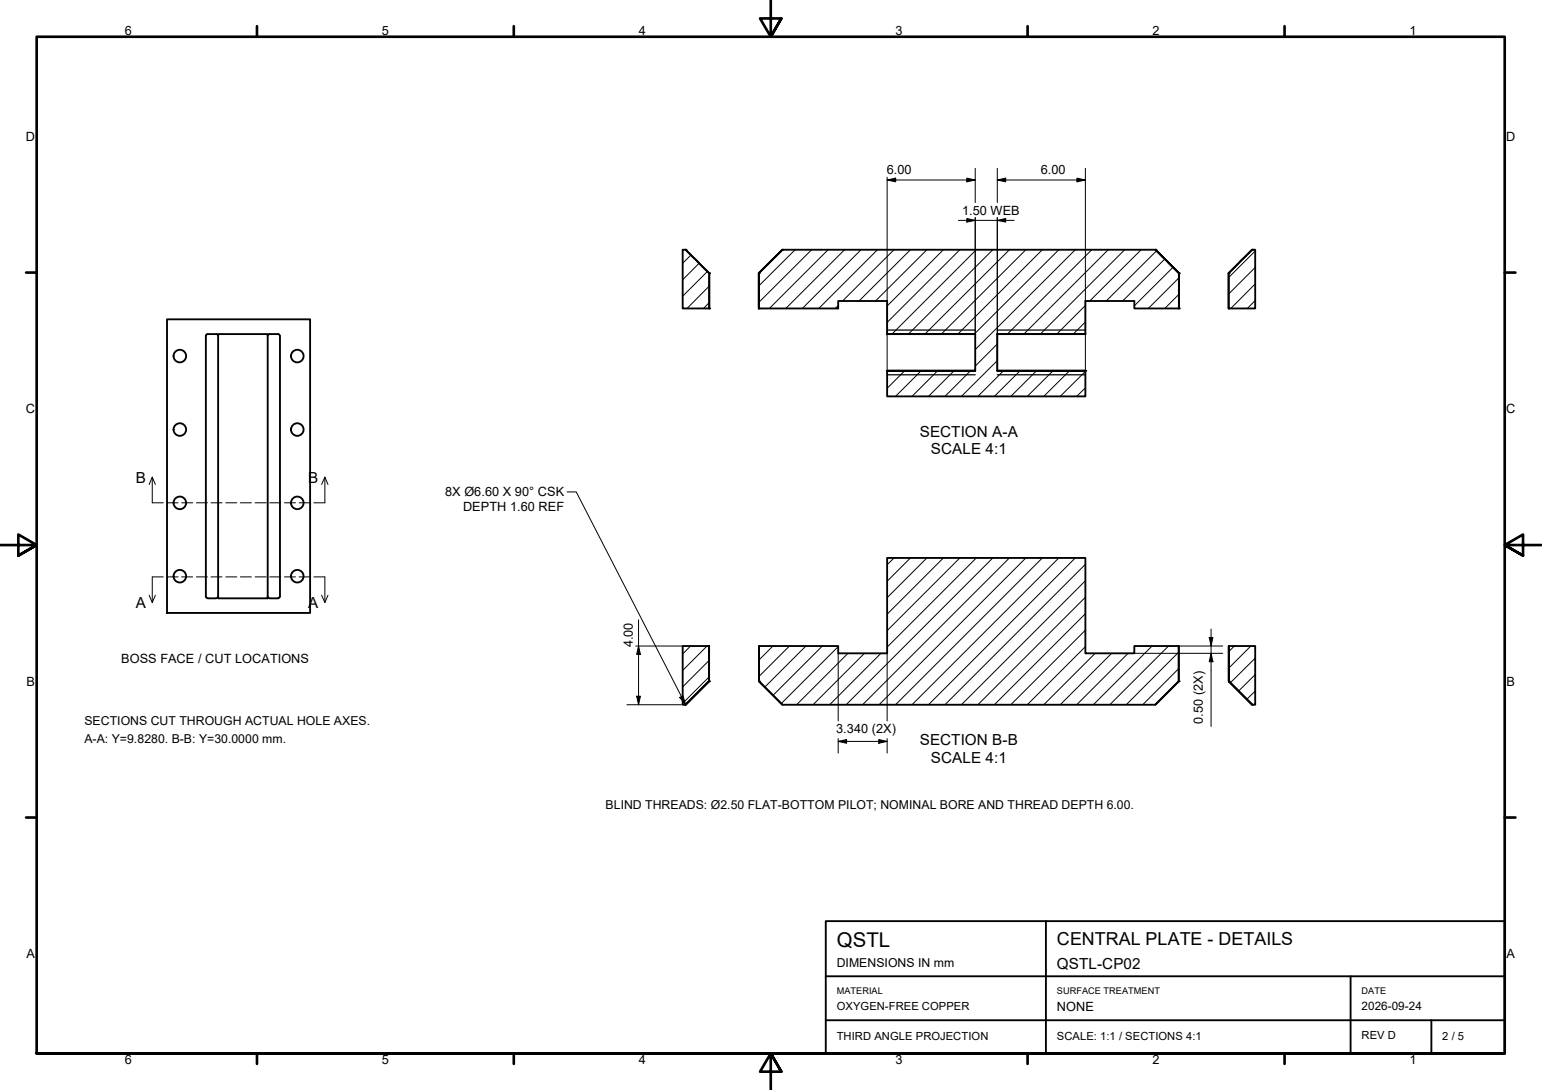
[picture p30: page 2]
SECTION A-A SCALE 4:1; SECTION B-B SCALE 4:1; 1.50 WEB; 8X Ø6.60 X 90° CSK DEPTH 1.60 REF

BOSS FACE / CUT LOCATIONS

SECTIONS CUT THROUGH ACTUAL HOLE AXES.

BLIND THREADS: Ø2.50 FLAT-BOTTOM PILOT; NOMINAL BORE AND THREAD DEPTH 6.00.

QSTL DIMENSIONS IN mm | CENTRAL PLATE - DETAILS QSTL-CP02

MATERIAL | SURFACE TREATMENT | DATE

THIRD ANGLE PROJECTION | SCALE: 1:1 / SECTIONS 4:1 | REV D | 2 / 5

4X Ø3.40 THRU THROUGH 1.60 FLANGE; ROD CONTACT FACE; DECK JOINT FACE; CONTACT FOOTPRINT: 6.00 X 80.00

C1.6 X 45 DEG - OUTER EDGE

NOMINAL DEPTH 6.50
Ø2.50 FLAT-BOTTOM PILOT
ENTRY FROM DECK JOINT FACE

BLIND-HOLE BOTTOM WALL: 2.00 REF

LEFT / RIGHT PARTS ARE NOT INTERCHANGEABLE.

QSTL DIMENSIONS IN mm | LEFT ROD SUPPORT QSTL-LS01

MATERIAL | SURFACE TREATMENT | DATE

THIRD ANGLE PROJECTION | SCALE: 2:1 / ISO 1.5:1 | REV D | 3 / 5

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

C1.6 X 45 DEG - OUTER EDGE

NOMINAL DEPTH 6.50
Ø2.50 FLAT-BOTTOM PILOT
ENTRY FROM DECK JOINT FACE

BLIND-HOLE BOTTOM WALL: 2.00 REF

LEFT / RIGHT PARTS ARE NOT INTERCHANGEABLE.

QSTL DIMENSIONS IN mm | RIGHT ROD SUPPORT QSTL-RS01

MATERIAL | SURFACE TREATMENT | DATE

THIRD ANGLE PROJECTION | SCALE: 2:1 / ISO 1.5:1 | REV D | 4 / 5

SECTION C-C SCALE 2:1; EXPLODED ASSEMBLY; SCALE 1.55:1; 8X DIN 7991 - M3 X 10 PITCH 0.5; 90° COUNTERSUNK; SCALE 1.25:1; OUTER FACE

ASSEMBLED - BOSS SIDE

QSTL DIMENSIONS IN mm | PLATE ASSEMBLY QSTL-AS01

MATERIAL CP / LS / RS: OFC | SURFACE TREATMENT | DATE

THIRD ANGLE PROJECTION | SCALE: AS SHOWN | REV D | 5 / 5

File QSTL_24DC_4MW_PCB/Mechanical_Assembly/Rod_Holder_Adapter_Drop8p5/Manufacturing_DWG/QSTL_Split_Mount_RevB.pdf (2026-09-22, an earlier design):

BOSS FACE; RIGHT SIDE; SEE CP02, SECTION B-B

5X M3 X 0.5 - 6H, DEPTH 6.00
EACH SIDE (10 TOTAL); Ø2.50 PILOT
SEE CP02, SECTION A-A

8X Ø3.40 THRU
Ø6.60 X 90° CSK FROM OUTER FACE
SEE CP02, SECTION B-B

2X DEVICE LIP RELIEF

3.340 WIDE X 0.50 DEEP; R0.50 CORNERS

QSTL DIMENSIONS IN mm | CENTRAL PLATE + BOSS QSTL-CP01

MATERIAL OXYGEN-FREE COPPER | SURFACE TREATMENT NONE | DATE 2026-09-22

THIRD ANGLE PROJECTION | SCALE: 1.5:1 / ISO 1:1 | REV B | 1 / 5

SECTION A-A SCALE 4:1; SECTION B-B SCALE 4:1; 1.50 WEB; 8X Ø6.60 X 90° CSK DEPTH 1.60 REF

BOSS FACE / CUT LOCATIONS

SECTIONS CUT THROUGH ACTUAL HOLE AXES.

BLIND THREADS: Ø2.50 FLAT-BOTTOM PILOT; NOMINAL BORE AND THREAD DEPTH 6.00.

QSTL DIMENSIONS IN mm | CENTRAL PLATE - DETAILS QSTL-CP02

MATERIAL | SURFACE TREATMENT | DATE

THIRD ANGLE PROJECTION | SCALE: 1:1 / SECTIONS 4:1 | REV B | 2 / 5

4X Ø3.40 THRU THROUGH 4.00 FLANGE; ROD CONTACT FACE; DECK JOINT FACE; CONTACT FOOTPRINT: 6.00 X 80.00

NOMINAL DEPTH 6.50
Ø2.50 FLAT-BOTTOM PILOT
ENTRY FROM DECK JOINT FACE

BLIND-HOLE BOTTOM WALL: 2.00 REF

LEFT / RIGHT PARTS ARE NOT INTERCHANGEABLE.

QSTL DIMENSIONS IN mm | LEFT ROD SUPPORT QSTL-LS01

MATERIAL | SURFACE TREATMENT | DATE

THIRD ANGLE PROJECTION | SCALE: 2:1 / ISO 1.5:1 | REV B | 3 / 5

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

NOMINAL DEPTH 6.50
Ø2.50 FLAT-BOTTOM PILOT
ENTRY FROM DECK JOINT FACE

BLIND-HOLE BOTTOM WALL: 2.00 REF

LEFT / RIGHT PARTS ARE NOT INTERCHANGEABLE.

QSTL DIMENSIONS IN mm | RIGHT ROD SUPPORT QSTL-RS01

MATERIAL | SURFACE TREATMENT | DATE

THIRD ANGLE PROJECTION | SCALE: 2:1 / ISO 1.5:1 | REV B | 4 / 5

SECTION C-C SCALE 2:1; EXPLODED ASSEMBLY; SCALE 1.55:1; 8X DIN 7991 - M3 X 10 PITCH 0.5; 90° COUNTERSUNK; SCALE 1.25:1; OUTER FACE

ASSEMBLED - BOSS SIDE

QSTL DIMENSIONS IN mm | PLATE ASSEMBLY QSTL-AS01

MATERIAL CP / LS / RS: OFC | SURFACE TREATMENT | DATE

THIRD ANGLE PROJECTION | SCALE: AS SHOWN | REV B | 5 / 5

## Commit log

2026-03-17 feature : schematic is done
    [QSTL_24DC_4MW_PCB.PcbDoc, QSTL_24DC_4MW_PCB.PcbLib, QSTL_24DC_4MW_PCB.PrjPcb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]
2026-09-20 Update existing carrier with routed ZIF layout and tented vias
    [PIN_MAPPING.csv, Passives_0603.PcbLib, QSTL_24DC_4MW_PCB.PcbDoc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]
2026-09-21 Complete six-channel RF carrier layout, shielding and fabrication documentation
    [Capacitors_0402.PcbLib, L5_L6_shield_microvias.csv, PIN_MAPPING.csv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]
2026-09-21 Move lower RF bias pairs inward and remove unused RF pad vias
    [L5_L6_shield_microvias.csv, QSTL_24DC_4MW_PCB.PcbDoc, stackup.csv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]
2026-09-22 Add simplified PCB assembly with Top_ForFridge carrier and fit verification
    [Bottom.ipt, Bottom_reference.step, C1.ipt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]
2026-09-22 Add inward-facing probe mount, sleeve and pocket distance drawing
    [Device_M3x8_Simplified.ipt, Device_M3x8_Simplified.step, Probe_H_Frame.ipt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]
2026-09-22 Add split mount CAD and native DWGs with standard M3 hardware
    [Centre_Plate.ipt, Centre_Plate.step, DIN_7991_M3x10.ipt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]
2026-09-25 Update M1 ZIF mounts, DC pours, CAD drawings and HDI fabrication
    Use 1.2 mm ZIF-end clearance holes and supplied M1 round-head hardware,
    with dimensioned cable clearance and saved native Inventor fit reports.
    Include the even-contact DC remap, 0.20 mm DC ground-pour clearance,
    1.6 mm rod-support flanges, standard round-head rod screws and Rev E DWGs.
    Regenerate the HDI CAM package with 96 through holes, 480 L5-L6 blind
    laser holes, Bottom blind-milling data and 50-ohm stack requirements.
    Saved PCB validation: zero DRC violations across 16 rules and all
    37 nets independently connected; current CAM geometry checks pass.
    [FPC_51_0p3_Envelope.ipt, FPC_51_0p3_Envelope.step, ISO_4762_M1p6x4.ipt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]
2026-09-30 Add validated split-mount STEP parts and current mechanical views
    [CP-01_Centre_Plate.step, LS-01_Left_Rod_Support.step, RS-01_Right_Rod_Support.step]
2026-10-03 Add 70 mm branched FPC and Anton-mapped Micro-D adapter projects
    [A_FPC51_P030_STAGGERED.PcbLib, B_FPC51_P030_STAGGERED.PcbLib, C_FPC51_P030_STAGGERED.PcbLib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]
2026-10-17 Refine RF entries and masks; widen QD bond pads
    Preserve smooth SMP entry shielding, add the L5 C/R cutouts, reduce oversized solder masks, and widen all 38 QD pads to 0.260 mm. Include saved native DRC, connectivity, mask/paste verification and r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
